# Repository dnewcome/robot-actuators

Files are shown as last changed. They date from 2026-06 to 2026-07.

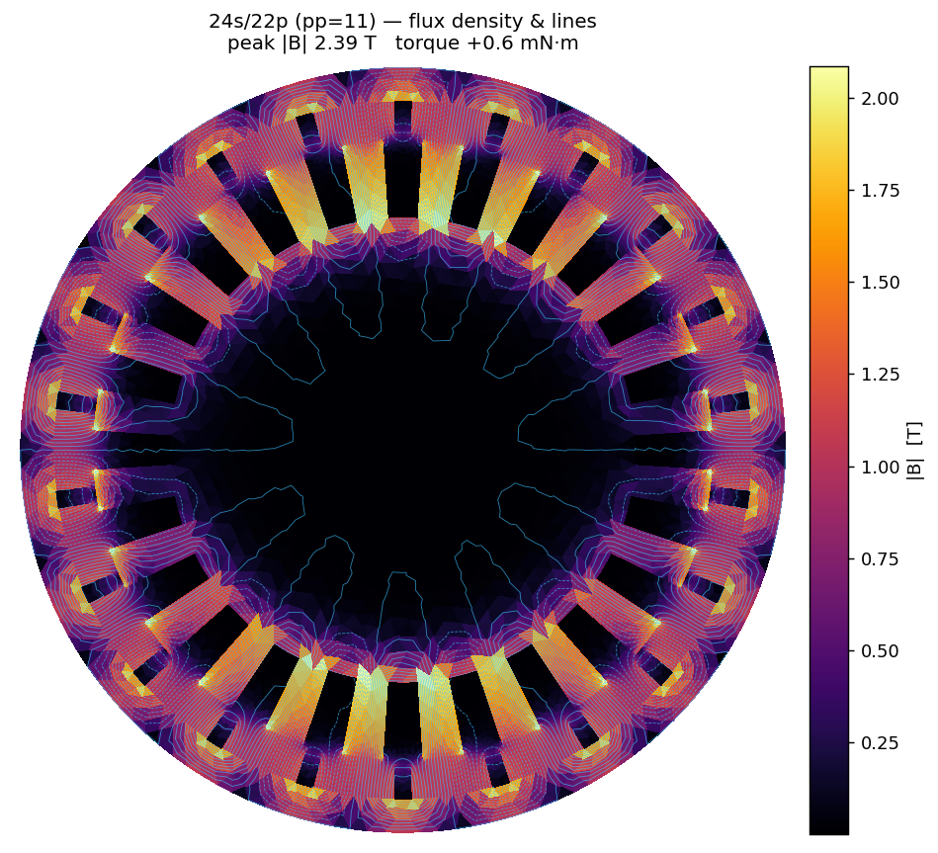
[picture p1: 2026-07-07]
motor/out/field.png

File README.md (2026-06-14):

# Robot Actuators

Designing my own actuators for robot arms (and, longer term, broader robotics /
automation) — and, just as importantly, building a **simulate-first pipeline** so a
parametric CAD design flows straight into a physics sim before anything gets printed
or wired up.

The north star: change a parameter, re-run, and immediately see both the geometry
*and* the predicted torque / speed / inertia behavior — fast enough to screen many
designs without touching a dyno.

---

## The idea

I've used other people's actuator designs (cycloidal drives, etc.) and want to design
my own. The broad wish-list spans very different physics:

- Dyneema capstan / cable drives
- Hybrid electric-hydraulic linear actuators
- Linear brushless motors
- BLDC motors built for servo use (quasi-direct-drive)
- Cycloidal, wave, and harmonic (strain-wave) drives
- Compliant / gearless drives
- Exotic "muscle" actuators — SMA / memory wire, wax motors / heat drives

**Prior experience:** used others' cycloidal drives; experimented with linear actuators
including **peristaltic pumps driving cylinders**; experimented with **wax motors / heat
drives** and **SMA "muscles"** for silent actuation (SMA judged not viable alone, but a
useful jumping-off point).

### The organizing theme

The list isn't "actuators broadly" — the through-line is **quiet, compliant, low/no-gear
actuation for arms.** That filter sorts the list onto a spectrum:

```
  buildable / proven  ─────────────────────────────►  exotic / risky
  Dyneema capstan      QDD BLDC servo        SMA / wax muscle
  (silent, backdrivable,  (force-transparent,   (truly gearless & silent,
   ~95%/stage, light)      low/no gearing)       low η, slow, hard to control)
```

- **Fits the theme:** capstan, QDD-BLDC, exotic muscles.
- **Fights it:** cycloidal / harmonic / wave (geartrains — high torque density but the
  thing we're trying to avoid for silence/compliance) and electro-hydraulic (noisy/messy).
- Cycloidal still wins **when compactness is the binding constraint** — which is exactly
  the case for the current build.

---

## Simulate-first philosophy: two layers

The hard-won insight that shapes this whole repo:

> **MuJoCo cannot tell you the efficiency of a drive.** It's a rigid-body engine for
> *control and whole-system behavior*. When you give a joint a gear ratio and a friction
> loss, you are **typing in** the efficiency, not discovering it. The 70%-vs-90% question
> lives one layer below where MuJoCo operates.

So the problem splits cleanly:

**Layer A — "Does this actuator make the arm work?" → MuJoCo.**
Model each joint with a parametric actuator (gear ratio, reflected inertia, mass, a
load-dependent efficiency, and a back-EMF torque-speed curve). Output: the torque/speed/mass
envelope each joint needs. This is what MuJoCo is good at, and it's wired up today (`mujoco/`).

**Layer B — "Can this drive beat the efficiency ceiling?" → analytical, NOT a sim.**
Capstan efficiency = capstan equation + cable-bend hysteresis + bearing drag; gear
efficiency = mesh-friction formulas. These evaluate in microseconds — faster and more
trustworthy than any sim for *efficiency*. Escalate to FEA / multibody contact only near a
margin. A digital torque meter validates a single point. **Layer B v0 exists**
(`cycloidal/efficiency.py`): it predicts η per contact strategy and feeds that number into
the sim — so the MuJoCo η is no longer a hand-typed guess. The model's coefficients are
*calibration-pending* (one torque-meter point pins them down); the relative ranking of
strategies is already robust (see "Efficiency model" below).

CAD feeds both: mass/inertia → MuJoCo; key dimensions → the analytical model. And the loop
is closed: **Layer B predicts η → Layer A (the sim) consumes it**, all from the same Params.

---

## Repository layout

```
robot-actuators/
├── README.md
├── .venv/                     # python env (build123d, bd_warehouse, mujoco, numpy)
├── cycloidal/
│   ├── drive.py               # parametric build123d generator + feasibility validator (both stages)
│   ├── gears.py               # involute planetary gears: spur (sun/planet) + custom internal ring
│   ├── efficiency.py          # Layer B: two-stage η (planetary × cycloidal) + needle-bearing sweep
│   └── out/                   # generated .step + .stl for all 8 parts + assembly.step
└── mujoco/
    ├── actuator.py            # MotorSpec + ActuatorSpec: motor × total ratio → joint + servo numbers
    ├── testbench.xml          # Layer-A sizing scene (real meshes + load arm + payload)
    ├── run.py                 # injects physics + Layer-B η; runs sizing scenarios; --view demo
    └── viewer_scene.xml       # real-time kinematic demo of the full hybrid (both stages)
```

---

## Quickstart

```bash
# one-time setup
python3 -m venv .venv
.venv/bin/pip install build123d bd_warehouse mujoco numpy   # bd_warehouse = involute spur gears

# 1) generate CAD (edit Params in cycloidal/drive.py, then):
.venv/bin/python cycloidal/drive.py        # prints feasibility report, writes cycloidal/out/*

# 2) Layer-B efficiency model (η per contact strategy + needle-bearing fit sweep):
.venv/bin/python cycloidal/efficiency.py

# 3) actuator spec sheet (motor × gearbox -> joint numbers):
.venv/bin/python mujoco/actuator.py

# 4) Layer-A sizing sim (headless; uses the Layer-B η; prints lift / backdrive scenarios):
.venv/bin/python mujoco/run.py

# 5) look at the mechanism (real-time, needs a display):
.venv/bin/python mujoco/run.py --view
```

> Note: `source .venv/bin/activate` also works, but calling `.venv/bin/python` directly
> avoids the "Permission denied" you get from trying to *execute* `activate` instead of
> sourcing it.

---

## Current build: concentric hybrid planetary + cycloidal (40:1)

A fully **concentric compound**: the motor's high rpm goes through a **planetary first stage**,
whose carrier drives the **cycloidal eccentric**, whose disc drives the output — all on one
axis. Total reduction is the product of the two stages:

```
motor ─► PLANETARY 4:1 (sun in, ring fixed, carrier out) ─► cycloidal ECCENTRIC
      ─► CYCLOIDAL 10:1 (ring fixed, carrier out) ─► output flange      = 40:1
```

**Why split the ratio** (and put the cycloidal *last*):
- The planetary runs at high speed / low torque — the regime where gears are efficient — so a
  small ~97% stage buys 4× ratio cheaply and keeps the cycloidal **chunky** (fat rolling pins,
  healthy eccentricity) instead of forcing tiny high-lobe-count geometry to hit 40:1 alone.
- The cycloidal has the **lowest backlash**, so making it the output stage puts the precision
  where it counts; the planetary's lash divides by the cycloidal ratio when referred to output.

Single-stage cycloidal is still available — set `planetary=False` (ratio falls back to the lobe
count). Compactness is the binding constraint throughout, which is why this beats a capstan here.

### Motor — Goolsky / Surpass 2204 1400KV (measured)

| Spec | Value |
|---|---|
| Can / weight | Ø28 × 22 mm, ~28.7 g |
| Poles / config | 12N / 14P outrunner |
| Shaft | 3 mm, **exits on the mount side** |
| Mount | M3 cross pattern: one hole pair **16 mm** apart, the perpendicular pair **19 mm** apart |
| Electrical | 1400 KV, ~13 A burst, 0.307 Ω, 7–15 V (3S nominal) |

Because the shaft exits the mount side, the gearbox bolts to the motor base and the shaft
drives the eccentric directly — the arrangement the design assumed.

### Planetary stage parameters (all feasibility checks PASS)

| Param | Value | Notes |
|---|---|---|
| Ratio | **4.0:1** | `1 + n_ring/n_sun`; sun in, ring fixed, carrier out |
| Teeth (sun / planet / ring) | 12 / 12 / 36 | `n_ring = n_sun + 2·n_planet`; module 0.75 mm (printable teeth) |
| Planets | 4 | equal-spaced: `(n_sun+n_ring) % n_planets == 0` |
| Gear Ø (PCD) | sun Ø9 / planet Ø9 / ring Ø27 | sun bores over the 3 mm motor shaft |
| Mesh quality | machined (~97%) | `planet_material` sets stage η (`printed` ~94%) |

Geometry is generated as real involute teeth (`cycloidal/gears.py`): external `SpurGear`s for
the sun and planets, and a custom involute **internal** ring gear (no library has one). The
validator checks tooth-count identity, equal-spacing, planet-to-planet collision, ring-fits-
housing, and sun-clears-shaft.

### Cycloidal stage parameters (all feasibility checks PASS)

| Param | Value | Notes |
|---|---|---|
| Ratio | **10:1** | lobe count; 11 ring pins, 10-lobe disc |
| Pin circle / housing OD | Ø32 / Ø39 mm | gearbox is larger than the can, as expected |
| Ring pins | 11 × Ø3 mm | steel dowels / cut rod |
| Eccentricity (E) | 0.70 mm | profile smoothness R/(E·N) = 2.08 (ideal) |
| Center bearing | 6700 (10×15×4) | gives a comfy 2.8 mm eccentric cam wall |
| Output pins | 6 × Ø2.5 mm | 0.85 mm clearance both sides of the lobe-root band |

### The feasibility validator — why it matters

Miniature cycloidals fail on **radial real estate**, not the lobe profile: the eccentric
cam must fit the 3 mm shaft + a wall + the offset + a bearing, and the output-pin circle
must live in the thin band between the center-bearing OD and the lobe root. `drive.py`
reports all those clearances **before** meshing geometry, so an infeasible design is caught
in milliseconds instead of in CAD or on the printer. (It already caught one bad config
during this build.)

Geometry is also checked, not just assumed: the generated disc has the correct **10 lobes**,
lobe depth **1.40 mm = 2E** exactly, and nests inside the Ø32 pin circle.

---

## 3D printing

Every run of `drive.py` writes **watertight STLs** (verified — slicers accept them) plus STEP
files. The parts assemble on a **single axial datum** (`Params.stack()`) into an enclosed can —
the same datum drives the viewer, so the CAD and the animation can't disagree.

| Part | STL bbox (mm) | Role / print notes |
|---|---|---|
| `housing.stl` | Ø40 × 20.5 | integrated case: motor-mount flange + **stepped cavity** (wide for the planetary ring, narrow for the cyclo disc) + cyclo pin pockets + cap bolts. Print flat (flange down). |
| `output_cap.stl` | Ø40 × 8 | end cap with the **688 output-bearing pocket** + hub through-hole + 4 bolts |
| `planet_ring.stl` | Ø34 × 4 | internal involute ring gear; presses into the housing's planetary seat |
| `carrier_eccentric.stl` | Ø30 × 6.5 | **merged** planet carrier + eccentric journal; planet-dowel holes + offset cam boss |
| `disc.stl` | Ø30 × 5 | the cycloidal disc; print flat, fine layers (0.1 mm) for the lobe profile |
| `output_carrier.stl` | Ø26 × 9.5 | output flange + **Ø8 hub** (the output shaft, rides in the cap bearing) |
| `sun.stl` / `planet.stl` | Ø10.5 × 4 | module-0.75 involute gears (sun bored for the shaft, planets for their dowels) |

**Bill of non-printed materials** (`drive.py`'s `hardware_bom()`):
- 11 × Ø3 mm steel dowel (ring pins — **free-spinning** rollers in the default `pin_mode="rolling"`)
- 6 × Ø2.5 mm steel dowel (output pins — pressed into the output carrier)
- 4 × Ø1.5 mm steel dowel (**planet idlers** — press into the carrier; planets spin on these)
- 1 × **6700** bearing (10×15×4) on the carrier's eccentric journal
- 1 × **688** bearing (8×16×5) in the end cap (output support)
- **planetary gearset** — Ø9 sun + 4 × Ø9 planet + Ø27 internal ring, module 0.75 (machined/MOD
  gears for η + durability, or SLA-printed for a prototype)
- 8 × M3 screws (4 motor cross-mount @ 16/19 mm + 4 end-cap)
- the Goolsky 2204 motor

> **Status — assembles into a printable can, not yet a finished drive.** The 8 parts now sit on
> a shared datum into an enclosed, supported actuator (motor flange ↔ output-bearing cap), with
> module-0.75 filleted gears, steel-dowel planet idlers, and explicit running/press clearances.
> Still to detail (see Roadmap): the motor **pilot boss**, the disc↔output-pin tolerances on your
> printer, and a balancing second disc. Gears at module 0.75 are printable on a 12k SLA but are
> still the first candidates to *machine/buy*. PETG or filled nylon recommended for the disc/cam.

## Manufacturing strategy: print the structure, machine the contacts

A cycloidal's efficiency lives almost entirely in a few **contact interfaces**, not in the
bulk parts. So the rule this project follows:

- **3D print the structure** — ring/housing body, carrier body, motor adapter. These just
  locate things; a 12k SLA gives accurate bores and bolt patterns, and resin tackiness
  doesn't matter where nothing slides.
- **Don't print the contact surfaces.** The places that rub set η, and SLA ABS-like resin
  is tacky (high μ) and wears under Hertzian contact — the worst material exactly where it
  matters most. This is *why* "print the housing, machine/buy everything else" is the right
  instinct.

The contacts, in order of efficiency leverage:

| Interface | Carries | v1 default | Efficiency upgrade |
|---|---|---|---|
| Eccentric ↔ disc center | radial reduction load | **6700 bearing** (already rolling) | — |
| Ring pin ↔ disc lobe | main reduction torque | fixed Ø3 steel dowel (**sliding**) | **rotating roller**: dowel core + hardened sleeve / needle bearing → rolling |
| Output pin ↔ disc hole | output torque | integral printed pin (sliding) | steel pin + **bronze / IGUS bushing or roller** |

**Biggest single lever: make the ring pins rotate.** A fixed pin *slides* against the lobe
(high loss); a pin (or sleeve) that *spins* turns that into rolling contact. This is most of
what separates a ~70% printed cycloidal from a ~90% one — largely independent of disc
material.

**The disc** is the other variable: SLA-print it for a prototype (12k gives a smooth lobe
profile, but tacky resin + wear cap durability and η), or step up to **machined POM/acetal**
(self-lubricating, low μ, cheap to machine) or metal for the real article. If the pins roll,
disc material matters mostly for *wear*, not friction.

This is also the **Layer B bridge**: which contacts roll vs slide, and the materials' μ, are
exactly the inputs the analytical efficiency model needs. The manufacturing choice and the
efficiency prediction are the same decision.

**This is now a `Param`, not a note.** `drive.py` encodes the contact strategy directly:

| Param | Options | Effect |
|---|---|---|
| `pin_mode` | `"fixed"` \| `"rolling"` (default) | press-fit dowel (sliding) vs free-spinning dowel in an oversized pocket (rolling) |
| `pin_core_dia` | `≤ pin_dia` | set `< pin_dia` for a hardened sleeve on a thin core (validator checks the sleeve wall) |
| `out_mode` | `"printed"` \| `"steel"` (default) \| `"bushing"` | integral printed pins (sliding) → pressed steel pins (sliding, good surface) → core + rotating bushing (rolling) |

The validator prints the resulting **contact strategy** (`ROLLING`/`SLIDING` per interface)
and checks sleeve/bushing wall thicknesses; `hardware_bom()` lists exactly what to buy for
the chosen modes. True rolling bushings on the *output* pins are tight at Ø2.5 — the
pragmatic default is rolling ring pins + pressed steel output pins.

## Efficiency model (Layer B v0) — can rolling elements help?

`cycloidal/efficiency.py` is the analytical half of Layer B. It predicts η from the contact
strategy (friction-coefficient based, coefficients **calibration-pending** — one torque-meter
point tunes them) and feeds that number straight into the sim. Predicted η by strategy:

| Strategy | ring / output contact | predicted η |
|---|---|---|
| all printed (worst) | sliding / sliding | ~65% |
| steel pins, sliding | sliding / sliding | ~77% |
| **default: rolling pins + steel output** | rolling / sliding | **~86%** |
| sleeves both | rolling / rolling | ~90% |
| needle bearings everywhere | rolling / rolling | ~93% |

**The finding:** most of the gain (65 → 86%, **+21 points**) is already captured by the cheap
default — free-spinning ring pins. Going further to full needle bearings adds only **+4–7
points**, and at this size it's mechanically awkward:

```
needle-bearing fit sweep (current Ø3 pins, housing Ø39):
  Ø2.5 loose-needle build ...... drop-in (replaces current pins)
  Ø4 loose-needle .............. grow drive to Ø26
  HK0408 drawn cup (Ø8) ........ grow drive to Ø44
  HK0509 drawn cup (Ø9) ........ grow drive to Ø48
```

So: **rolling ring pins are the high-value move; needle bearings are diminishing returns**
that cost compactness — unless you build the marginal Ø2.5 loose-needle rollers, which fit
as-is. The model's *relative* ranking is robust (driven by μ ratios); the absolute numbers
wait on the torque meter.

## How it's wired (single source of truth)

```
cycloidal/drive.py  ──(ratio)──►  mujoco/actuator.py  ──►  mujoco/run.py
      │                                                         │
      └──► out/*.stl ─────────────────► testbench.xml ◄─────────┘
                                        viewer_scene.xml
```

The **total ratio** (`planet_ratio × cyclo_ratio`) is pulled straight out of `drive.py` into
`actuator.py`, and `run.py` injects the derived armature / gear / friction onto the MuJoCo model
at load time. **Change a `Param`, re-run, and the geometry and the sim move together** — they
can't drift apart. `p.ratio` is the single number the whole sim sees, so going hybrid changed
nothing downstream except the value.

`actuator.py` turns motor constants × ratio into joint-level numbers:
`Kt = 60/(2π·KV)`, `peak τ = η∞·Kt·I·N − drag`, `no-load ω = KV·V/N`, `reflected J = J_rotor·N²`,
and the back-EMF current limit `I = (throttle·V − Ke·ω)/R`. η∞ now chains both stages
(`η_planet × η_cyclo`) and `drag` refers through the full ratio — both from `efficiency.py`
(Layer B), so the whole chain is one source of truth.

### Positioning / servo resolution (BLDC "step counts")

A BLDC has no native steps like a stepper — but **the reduction multiplies whatever the rotor
resolves**, which is the lever for servo accuracy. For the 14-pole motor (7 pole-pairs) at 40:1:

| Rotor sensing | counts / motor rev | × 40 → output | output resolution | holds at standstill? |
|---|---|---|---|---|
| Hall / back-EMF 6-step | 6 × 7 = 42 | 1,680 | **0.214°** | Halls yes; back-EMF **no** |
| magnetic encoder 14-bit | 16,384 | 655,360 | ~0.001° | yes (FOC) |

Output **backlash ~0.08°** (planet lash ÷ cyclo ratio + tiny cyclo lash) sits below the Hall
resolution, so 0.214° is usable, not swamped by slop — that's *why* the cycloidal is last.
**Back-EMF amplitude ∝ speed**, so it gives commutation + velocity for efficient cruising but
**cannot hold position at rest**; pair it with Halls (cheap 0.214°) or an encoder (precise) for
the holding loop. `actuator.py`'s `servo_report()` prints this table for the current Params.

### Torque-based (load-dependent) efficiency

Efficiency isn't a flat number — a roughly constant **no-load drag** must be overcome before
useful torque appears, so η rises from 0 toward η∞ as load grows. This is realized in the sim
for free: **gear carries η∞ (0.83), joint frictionloss carries the drag (80 mN·m at output)**,
which reproduces `η(T) = η∞·T/(T+drag)`. The *operating* efficiency therefore tops out ~81% at
peak torque (peak load ≠ infinite load), not 83%. η∞ is itself the two-stage product
(planetary 0.97 × cyclo 0.86).

### Back-EMF and the torque-speed curve

The motor is now driven by **throttle (voltage)**, not raw current. At speed it generates
back-EMF (`Ke = Kt`), so the available current is `I = (throttle·V − Ke·ω) / R`, clamped to
the 13 A rating. That yields the real two-regime envelope:

- **current-limited** (flat ~2.87 N·m) below the corner speed (~249 rpm out), where the rating
  caps the current;
- **voltage-limited** above it, torque drooping linearly to **zero at the 388 rpm no-load
  speed** as back-EMF eats the headroom.

No more freewheeling: a free spin settles at no-load speed instead of accelerating forever.

---

## Simulation results (hybrid 40:1, load-dependent η, η∞ = 0.83)

```
total ratio ....... 40:1       (planetary 4.0 × cycloidal 10)
η∞ (high-load) .... 83%        (planetary 0.97 × cyclo 0.86); no-load drag 80 mN·m (output)
PEAK torque ....... 2.87 N·m   (@ 13 A burst, net of drag)
cont. torque ~..... 0.89 N·m   (thermal-limited estimate)
no-load out speed . 388 rpm
reflected inertia . 24e-4 kg·m²   (scales with ratio²)
max static payload  ~1.95 kg @ 150 mm (peak) / ~0.61 kg (continuous)
output resolution . 0.214° (Hall × 40)   backlash ~0.08°
```

**Scenario A — free accel:** output reaches ~30 rad/s in 50 ms; simulated effective
inertia (46.8e-4) **matches the hand calc** of arm+payload+armature → the model is
trustworthy.
**Scenario B — lift 100 g @ 150 mm:** needs 0.16 of 2.87 N·m available → lifts easily.
**Scenario C — unpowered hold:** backdrives under load → **backdrivable**, the desired
property for a compliant, safe arm.
**Scenario D — efficiency vs load (measured in sim):** η climbs 32% → 46% → 59% → 69% as
output torque rises 0.05 → 0.40 N·m, and the **measured η matches the model** — the load
curve emerges from the gear+frictionloss physics, not a typed-in constant.
**Scenario E — torque-speed curve (traced in a sim spin-up):** under full throttle the
delivered torque holds ~2.87 N·m to ~249 rpm, then droops toward zero at 388 rpm — the
back-EMF envelope, measured as the output accelerates (sample points scale with no-load speed).

The `--view` demo is a real-time kinematic scene of the **whole hybrid**: the cycloidal
**output** turns at 0.25 rev/s, the **planet carrier** at 10×, the **gold sun** at 40×, and the
**4 green planets** orbit (10×) while spinning on their pins (−20×) — the full 40:1 chain visible
at a glance.

---

## Roadmap

**The exciting frontier: a full electromechanical drive model.** Done so far: efficiency is
**load-dependent** (η rises with torque ✓), **geometry-driven** (predicted from the contact
strategy ✓ Layer B v0), and the motor now has **back-EMF + a real torque-speed curve** driven
by throttle/voltage with current limiting (✓). What's left:

- **Winding inductance (L) + fast current dynamics** — the steady-state electrical model (R,
  V, back-EMF, current limit) is in; add L and explicit FOC for transient current response.
- **Thermal** — I²R heating → the *real* continuous-torque limit instead of a 1/3 guess.
- **Load-dependent bearing losses** — extend Layer B so the drag itself grows with the mesh
  force (the eccentric bearing reacts the load), refining the low-load end of the η curve.

One CAD edit already predicts geometry → efficiency(load) → torque-speed behavior before any
hardware exists. Remaining items refine transients (L/FOC) and thermal limits.

**Nearer-term:**
- **Calibrate the Layer B model** with one torque-meter point (the v0 model exists and feeds
  the sim; the coefficients are still estimates). Extend it with load-dependent bearing losses.
- Drop this actuator into the real arm MJCF as a reusable joint module.
- Detail the last hardware bits: motor **pilot boss**, disc↔output-pin tolerances, and the
  output shaft / arm-joint interface.
- Add a second cycloidal disc at 180° (or a counterweight) to balance before high rpm.
- Sweep the total ratio: bump to **44:1** (cyclo 11 lobes) or **48:1** (cyclo 12), or shrink the
  Ø40 case now that clearances are visible.
- Planetary detailing: backlash/profile-shift on the gears for real print fit.

**Done this iteration:** **integrated, printable assembly** — one enclosing case (motor flange +
stepped cavity + cyclo pockets) with a 688-supported output cap, module-0.75 filleted gears,
steel-dowel planet idlers, merged carrier+eccentric, and a single `stack()` datum shared by the
CAD assembly and the viewer (parts no longer interpenetrate).

**Prior iteration:** concentric **hybrid planetary + cycloidal (40:1)** — involute gears
generated (`gears.py`), two-stage η chained, total ratio flows through the whole sim, the full
compound animates in `--view`, and the BLDC **servo-resolution** model (ratio as a position
multiplier) is in `actuator.py`.

---

## Backlog / parked ideas

- QDD BLDC servo (Mini Cheetah / MIT style) — the modern quiet-arm path.
- SMA / wax "muscle" test rig — silent & gearless, high risk; research, not a deliverable.
- Electro-hydraulic linear actuators; peristaltic-pump-driven cylinders.
- Capstan / cable drive — the high-efficiency, silent play for when compactness isn't binding.
- Harmonic / wave drives; linear brushless motors.
- Broader "silent drive" survey.

---

## Caveats baked into the code

- **η is model-derived but calibration-pending.** Efficiency now comes from the Layer-B
  contact model (η∞ ≈ 0.86), is load-dependent, and feeds the sim — but the model's
  coefficients are estimates. One torque-meter point (no-load drag → `drag`; a loaded point →
  η∞) locks the absolute numbers. The *shape* (load-dependent, geometry-driven) is right; the
  *absolute* values aren't validated yet.
- **Electrical model is steady-state.** Back-EMF, resistance, bus voltage, and the current
  limit are in (real torque-speed curve), but winding inductance (L) and explicit FOC current
  dynamics are not — transient current response is idealized. Fine for sizing/torque-speed.
- **Continuous torque is a guess** (~1/3 of peak) until a thermal model replaces it.
- **The kinematic viewer treats the rotor as rigid** — the cycloidal disc's nutation isn't
  animated (it's a look-at-the-mechanism demo, not a contact simulation).

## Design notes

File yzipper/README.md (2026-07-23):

# Y-zipper — 3-strip flexible↔rigid element (paper-faithful rebuild)

*Rebuilt 2026-07-23 to follow the paper's ACTUAL algorithm (an earlier version used a
made-up "differential pitch → radius" rule + rectangular teeth, which did not match the
paper — the shapes came out wrong). Now grounded in Jiaji Li et al., "Y-zipper", ACM
CHI '26 — [doi:10.1145/3772318.3790723](https://dl.acm.org/doi/10.1145/3772318.3790723),
§3.1 (tooth geometry) + Appendix A.3 (primitive formulas).*

*A stiffness element, not a linear actuator — the actuator sibling is the 2-strip zip
chain in [`../zipchain/`](../zipchain/). The "actuator" here is the slider.*

> **Hardware in progress (2026-07-22):** test-printing a community "extended / optimized"
> three-sided Y-zipper ([MakerWorld 2888456](https://makerworld.com/en/models/2888456-y-zipper-extended-optimized-three-sided-zipper)).
> The measured per-tooth engagement force and the screw constant `k` are the two
> calibration-pending inputs the print pins down.

---

## Tooth geometry (§3.1) — what was wrong before

Each vertical **segment** is three teeth (a, b, c) with a **wave-like profile** that
**cyclically overlap** — left of a over right of b, b over c, c over a — a mutually
supporting ring that turns three flexible strips into a rigid triangular prism. Each
tooth carries a **ball node (∅1 = 2.4 mm)** on top and a **socket (∅2 = 3.0 mm)** below
(tol 0.3 mm) for shear/alignment, and **compliant bridges** (thickness D; TPU 0.6–2.4,
PLA 0.4–1.2) join segments and carry tension when zipped. *(The old model used uniform
rectangular castellations with none of this — hence "the output doesn't look right".)*

## Programming shapes = varying the teeth (Appendix A.3)

The four one-DOF primitives are **not** made by changing pitch; they come from the tooth
geometry:

| Primitive | Mechanism | Formula |
|---|---|---|
| **Straight** | uniform teeth | `z = v·t` |
| **Bend** | teeth at interface α–β **thinner** than α–γ; accumulate `T1, T2` | **θ = 2(T1−T2)/(√3·w)**,  **R = (T1+T2)/(2θ)** |
| **Screw** | shift each tooth's lower side up by Δt → ball-normal rotates | **θ_z = k·Δt**  (−1.5t ≤ Δt ≤ 2.5t),  L_z = √(L²−(r·θ_z)²), r = w/√3 |
| **Coil** | bend **+** axial rise Δz per segment | helix R, pitch h from `T1,T2,T3,Δz` |
| **Series** | primitives compose via homogeneous transforms | `r(t) = Σ Tᵢ₋₁·rᵢ(tᵢ)` |

The bend is a *bimetallic-strip* effect: a difference in accumulated tooth **thickness**
across the two interfaces, over the interface separation √3·w/2 (the triangle height),
bends the axis. `yzipper.py` also exposes the **design inverse** the Grasshopper tool
gives users: the (T1−T2) needed for a target angle (bend 90° → T1−T2 = 34.0 mm at w=25).

## Stiffness — the paper's MEASURED values (not an idealized calc)

Three-point bending (§9.2): **EI_strip ≈ 1.9×10³ → EI_rod ≈ 3.1×10⁵ N·mm² ≈ 160×**.
Beam stiffness `k = 48·EI/L³`; max load rises with bridge D (11 kg @ 0.8 mm → 18 kg @
2.0 mm). *(An idealized closed-thin-wall calc overpredicts ~400× because teeth + bridges
are not a solid tube — so the model is anchored to the measured numbers.)*

## Files

- **`yzipper.py`** — the primitive algorithm: `inc_straight/inc_bend/inc_screw/inc_coil`
  build each primitive from the Appendix A.3 equations, `_integrate` composes them via
  homogeneous transforms, and `out/primitives.png` **reproduces the paper's Fig. 6**
  (straight prism, bend arch, coil helix, screw twist, and a straight+90°-bend series).
  Calibrated stiffness/load report.
- **`cad.py`** — corrected tooth geometry: rounded **wave teeth + ball nodes + sockets +
  bridges** (`strip_straight`), and a **curved arc flat-pattern with differential tooth
  spacing** (`strip_bend`) that embodies the θ = 2(T1−T2)/(√3·w) bend; plus the 3-way
  `slider` and a `segment` prism. All watertight solids.
- **`sim.py`** — MuJoCo viewer: the closed rod is instanced along a paper-equation
  centreline; the slider zips base→tip and the **rigid (zipped) front advances** while
  the unzipped part stays translucent. `make sim-yzipper` (bend) / `sim.py coil`.

`make yzipper / yzipper-cad / sim-yzipper`.

---

## Sources
- Paper (open access PDF): https://groups.csail.mit.edu/hcie/files/research-projects/y-zipper/y-zipper.pdf
- Paper (ACM CHI '26): https://dl.acm.org/doi/10.1145/3772318.3790723
- Project page / video: https://hcie.csail.mit.edu/  · https://www.youtube.com/watch?v=AWig98GVIno
- Printable model being tested: https://makerworld.com/en/models/2888456-y-zipper-extended-optimized-three-sided-zipper

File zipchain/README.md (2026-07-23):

# Zip-chain linear actuator — research + Layer-B model

*Built 2026-07-22: `zipchain.py` (model) + `cad.py` + `sim.py`. This is **one of two
separate zipper-for-rigidity mechanisms** in the repo — the **LINEAR ACTUATOR**. Its
sibling, the **Y-zipper variable-stiffness element**, is a **different mechanism for a
different purpose** and lives in [`../yzipper/`](../yzipper/). They share only the
"mesh to make rigidity" trick; as devices they do different jobs — don't conflate them.*

| | **zip chain** (here) | **Y-zipper** ([`../yzipper/`](../yzipper/)) |
|---|---|---|
| strips | **2** | **3** |
| output | linear **thrust + stroke** (motion) | a **stiffness state** (flex↔rigid) |
| section | open, needs a guide | closed triangle, self-supporting |
| role | a linear **actuator** | a variable-stiffness / deployable **structure** |
| binding constraint | column **buckling** | tooth engagement / section stiffness |

---

## The mechanism (Tsubaki reference)

Two chain strands are fed into a sprocket head where they **interlock like a zipper**
into a single rigid pillar; run the sprocket backward and they separate and re-coil.
A normal chain only pulls — this one **pushes and pulls**, because the meshed column
carries compression, and the mesh **self-locks** so it holds a load with the motor off.

**Why it's genuinely different** from a ball screw / rack-and-pinion:
- **Compact storage → long stroke.** The strands store as two coils and deploy into a
  rigid strut (Tsubaki claims up to ~90% less floor area for a given stroke).
- **Push *and* pull** over the full stroke (rigid chain, not a cable).
- **Self-locking hold** at any position **without power** — ball screws can't.
- **Cheap to run** — < 1/30 the power of a comparable pneumatic/hydraulic cylinder.

Reference specs (industrial Zip Chain Actuator, medium/large): **38.2 kN**, **5,000 mm**
stroke, **1,000 mm/s**, **~90%** efficient with dedicated sprockets, 6M round trips,
multi-point stop, vertical-lift / horizontal-push / vertical-hang mounting.

## Why 2 strips — and why 3 is a different animal

Two strands zipped make an **open, near-flat section**: stiff to **in-plane** bending
only, weak out-of-plane and in torsion. Tsubaki gets away with it because the sprocket
**housing guides the weak axis** — it's a *guided push rod*. Add a third strip at 120°
and you get a **closed triangular tube** — rigid in every direction plus torsion, and
**self-supporting** with no guide. That extra rigidity is a different capability for a
different job (a stiffenable structure, not a push actuator) → it's the [`yzipper/`](../yzipper/)
thread, not this one.

## Fit to this repo

A **linear-actuator** cousin to `linear/` and `linear-rail-servo/`, but with a *different*
binding constraint — **column buckling**, not fluid compressibility or belt backlash. It
is **non-backdrivable with an energy-free hold**, which *fights* the repo's
quiet/compliant/backdrivable theme (like cycloidal does) yet **wins when the need is a
compact linear push that holds position with the motor off.** PLA-printable.

## The Layer-B model (BUILT — `zipchain.py`)

> **The binding constraint is COLUMN BUCKLING, not the motor.** The deployed free length
> is an Euler strut, so push capacity **falls as it extends**: `F_cr(L)=π²·E·I_col/(k·L)²`.
> Below a knee length **L\*** the actuator is drive/mesh-limited (flat); beyond L\* it is
> buckling-limited (∝1/L²). The push–stroke envelope is therefore **asymmetric** from the
> pull side (tension-limited by strand strength). `zipchain.py` exposes that envelope, a
> feasibility validator, and `out/envelope.png`.

Three design levers, all `Param`s: **column stiffness E·I** (section × engagement
fraction), **sprocket pitch radius r_p** (the gear ratio — trades thrust for deploy
speed, power-conserving), **end fixity k** (k=2 fixed-free cantilever conservative;
guided load end → k=1 quadruples F_cr).

**Default design results** (robot-scale, printed; calibration-pending strengths):

| Quantity | Value |
|---|---|
| deploy speed | **607 mm/s** @ 300 rpm (r_p = 19.3 mm, z=12) |
| drive thrust (τ/r_p) | **93 N** @ 2.0 N·m |
| push envelope | **93 N flat → 39 N** at full 320 mm extension |
| **buckling knee L\*** | **207 mm** (last ~⅓ of stroke is buckling-limited) |
| pull | 93 N flat (drive-limited; strand cap 1500 N) |
| hold @ full ext, motor off | **39 N** (mesh self-locks) |
| stored footprint | Ø81 mm for 300 mm stroke (store/stroke **0.27**) |

**`cad.py`** — 3 watertight solids: `strand` (a comb: outer spine + interlacing fingers),
`sprocket` (bored disc + z teeth), `head` (guide/merge housing that constrains the weak
axis). Two mirrored/half-pitch-staggered strands interlace into the deployed column.

**`sim.py`** — kinematic MuJoCo viewer: sprocket spin geared to column extension
(x=r_p·θ), column fed through the head; the montage annotates each frame with the push
capacity at that extension, so you watch the buckling ceiling fall as it deploys.
`make zipchain / zipchain-cad / sim-zipchain`.

---

## Sources
- Tsubaki Zip Chain (technology): https://en.tt-net.tsubakimoto.co.jp/tecs/pdct/sad/feat/pdct_feat_sad_ZC.asp
- Tsubaki Zip Chain Actuator (product): https://www.ustsubaki.com/products/zip-chain-actuator/

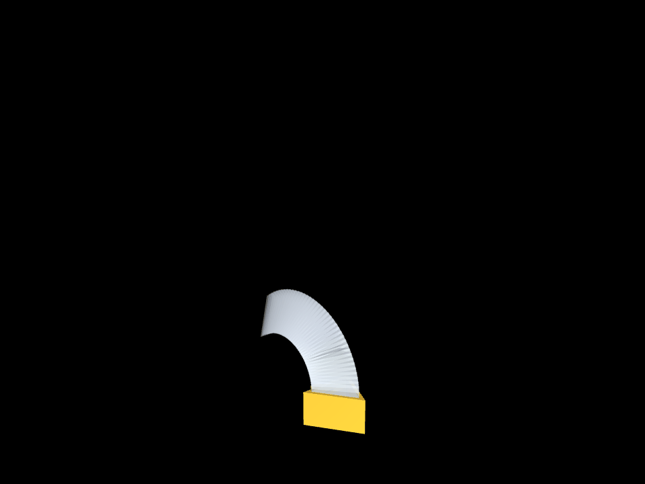
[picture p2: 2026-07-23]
yzipper/out/sim.gif

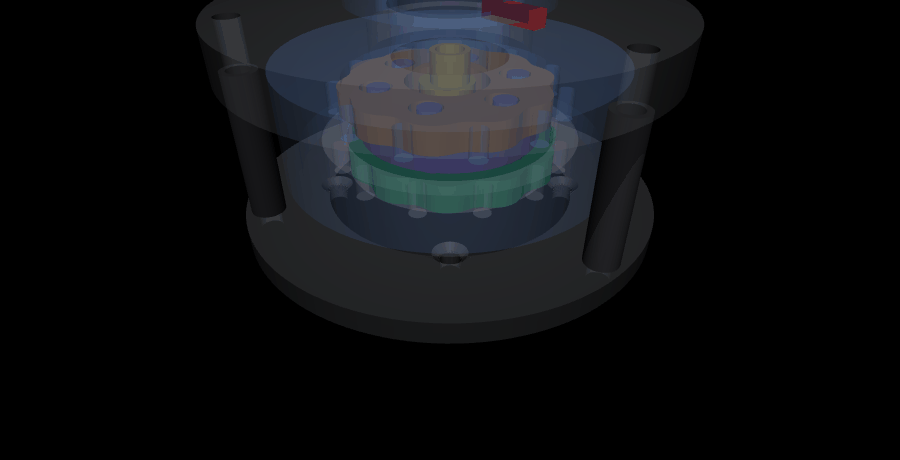
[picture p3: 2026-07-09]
cycloidal-2stage/out/sim.gif

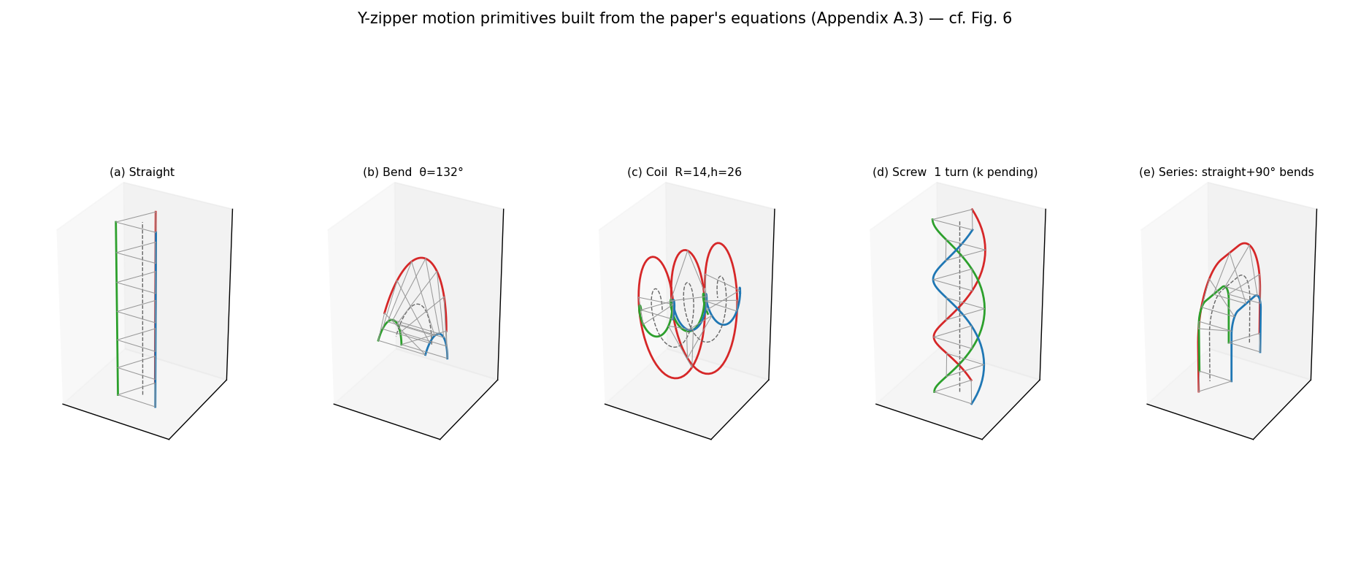
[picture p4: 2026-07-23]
yzipper/out/primitives.png

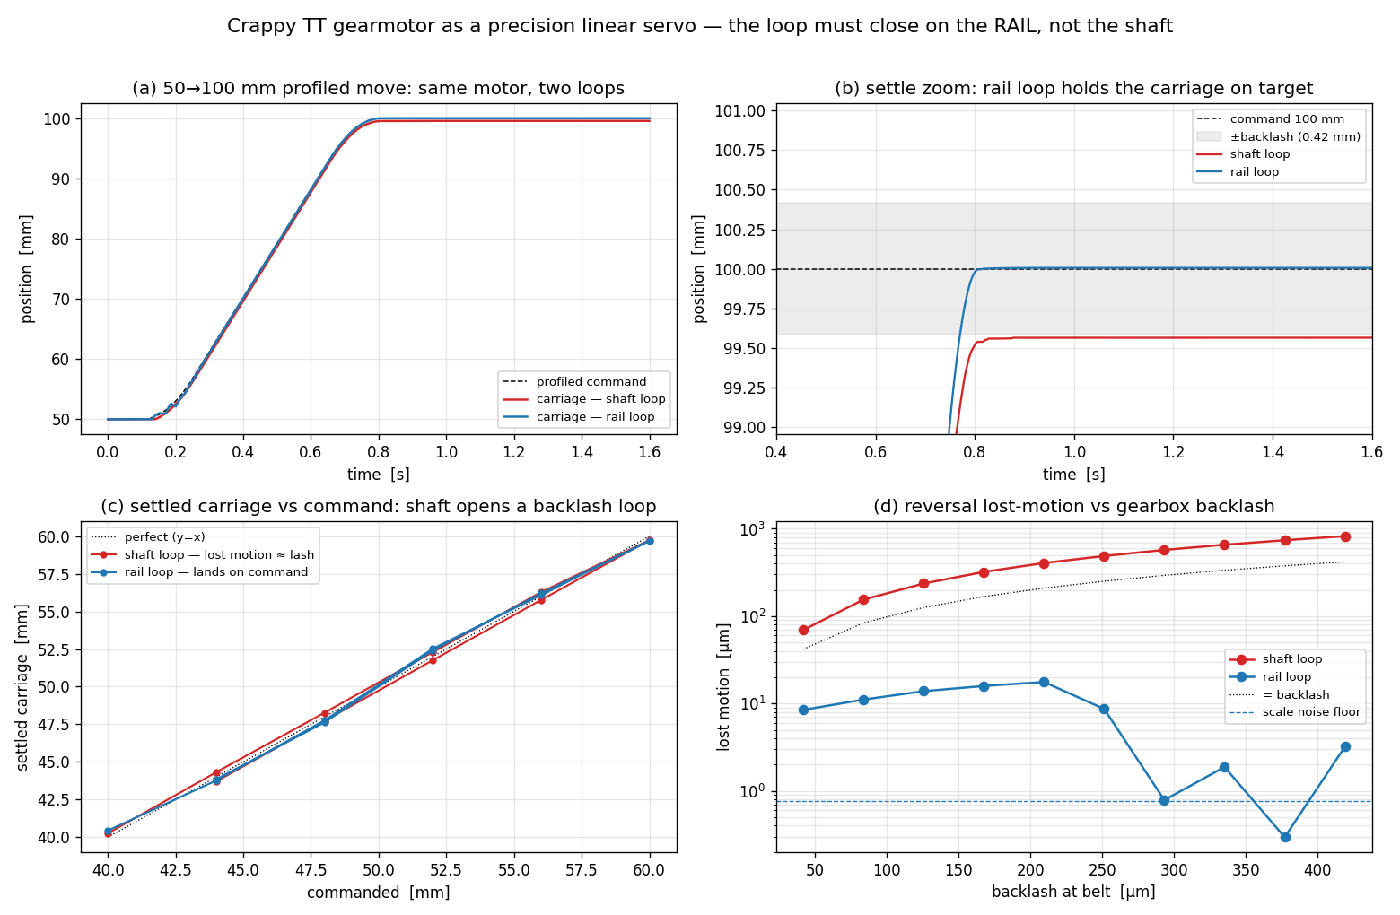
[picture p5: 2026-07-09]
linear-rail-servo/out/servo.png

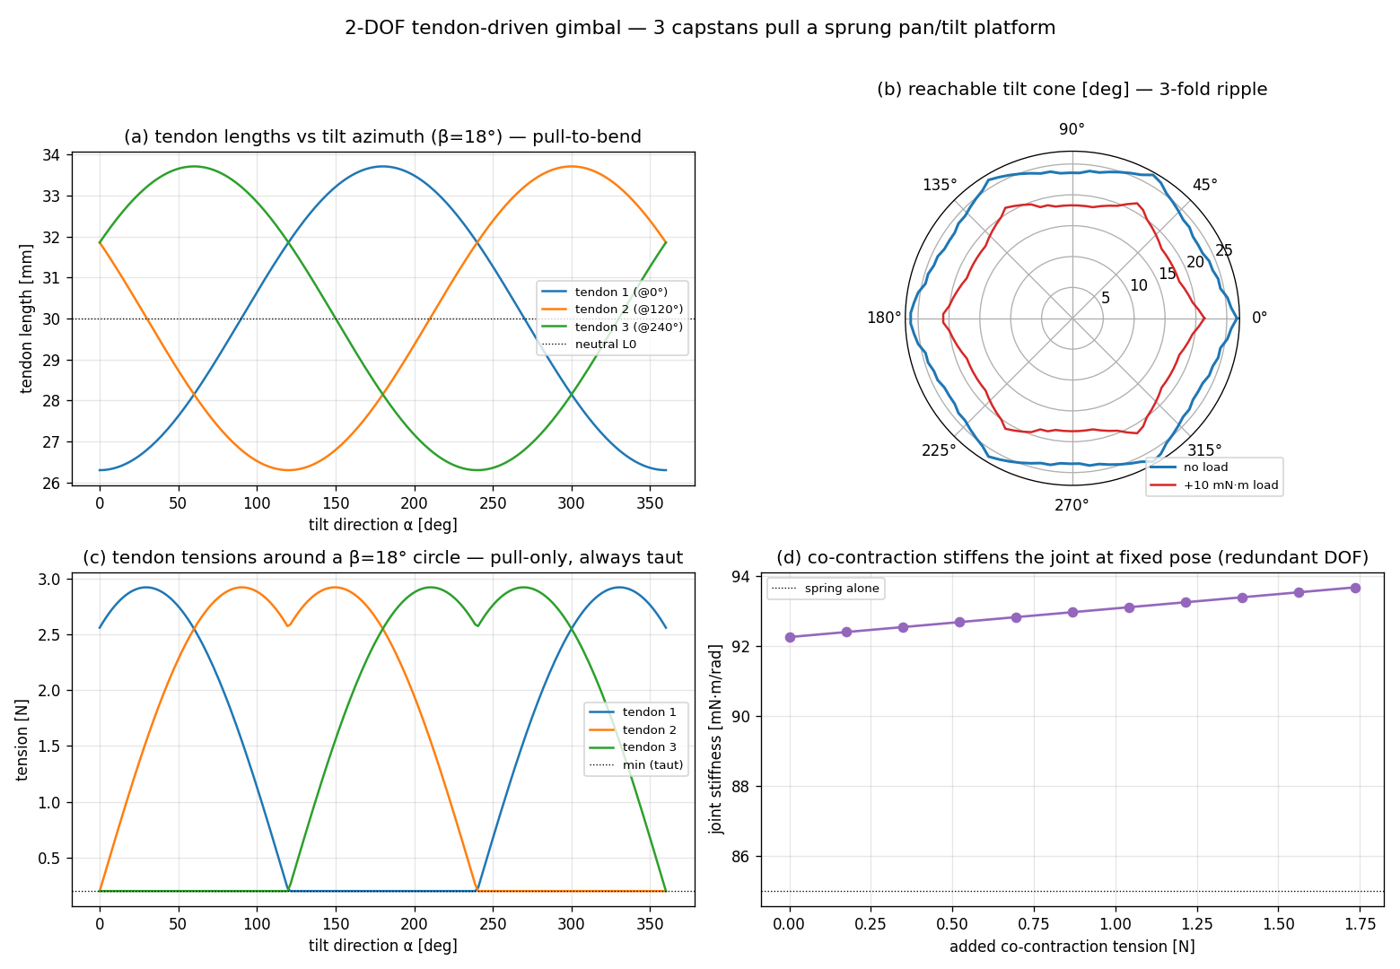
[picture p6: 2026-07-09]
flex/out/flex.png

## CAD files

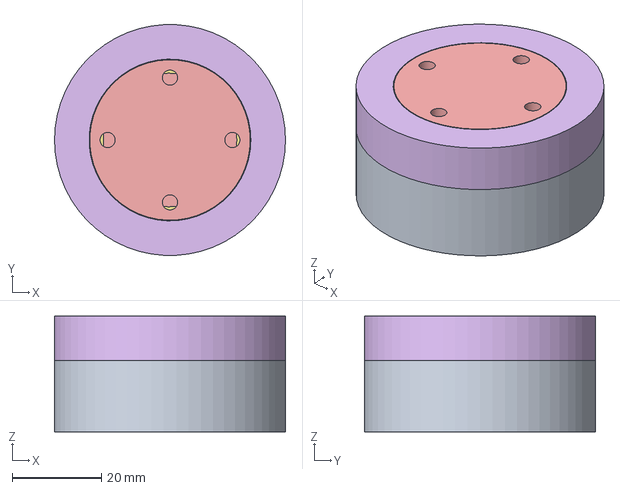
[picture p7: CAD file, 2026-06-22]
cycloidal-center/out/assembly_full.step
51.8 x 51.8 x 26.0 mm

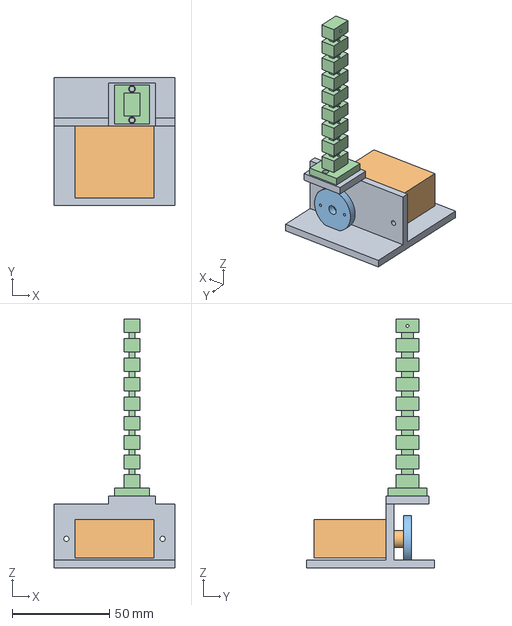
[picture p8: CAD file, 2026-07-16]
tendril/out/assembly.step
62.0 x 66.0 x 128.0 mm

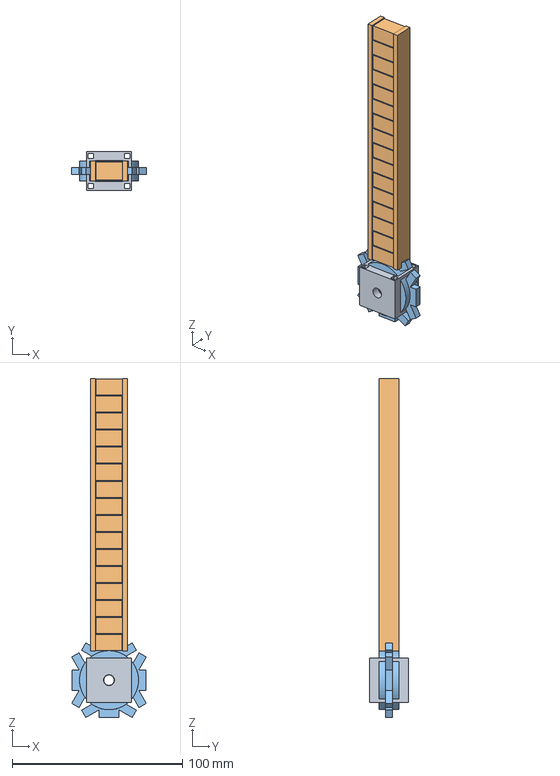
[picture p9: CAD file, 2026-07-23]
zipchain/out/assembly.step
43.8 x 22.6 x 198.9 mm

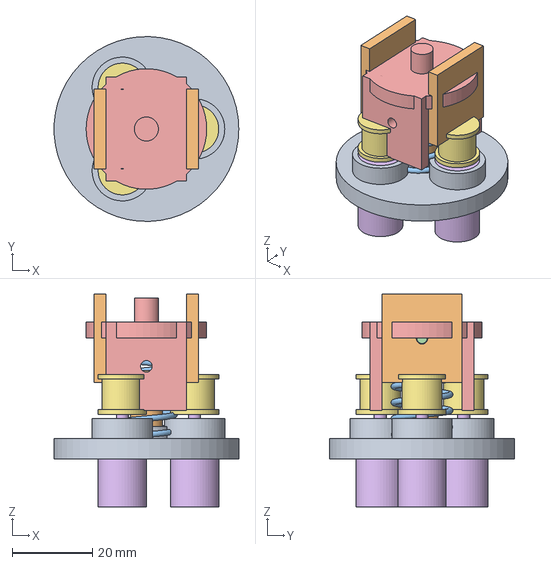
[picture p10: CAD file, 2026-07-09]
flex/out/assembly.step
46.0 x 46.0 x 53.0 mm

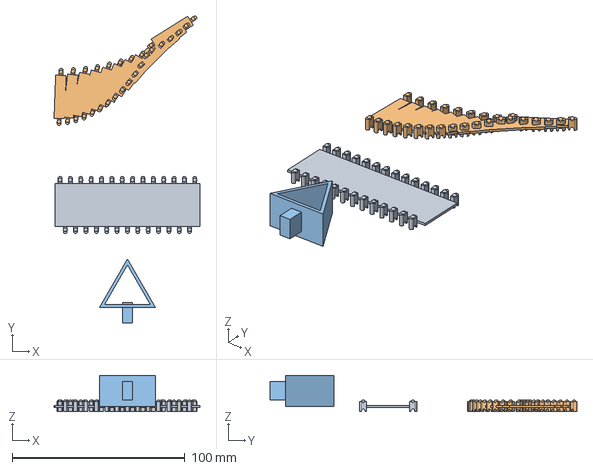
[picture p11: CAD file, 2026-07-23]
yzipper/out/assembly.step
84.5 x 177.7 x 21.0 mm

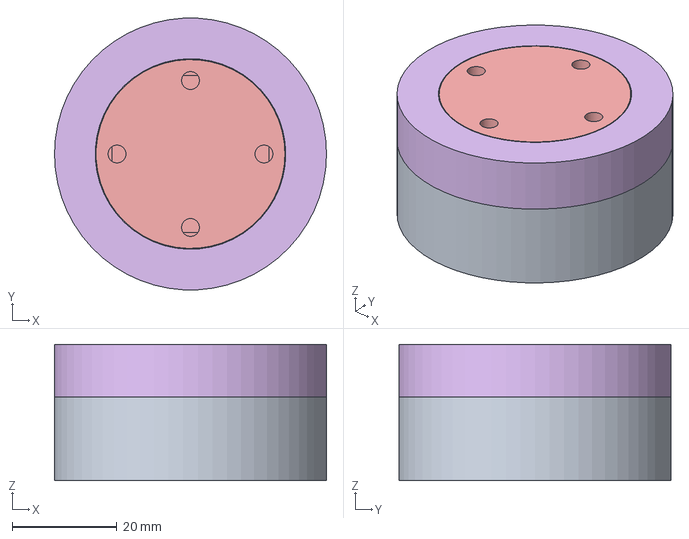
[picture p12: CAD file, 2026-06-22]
cycloidal-center/out/assembly.step
51.8 x 51.8 x 26.0 mm

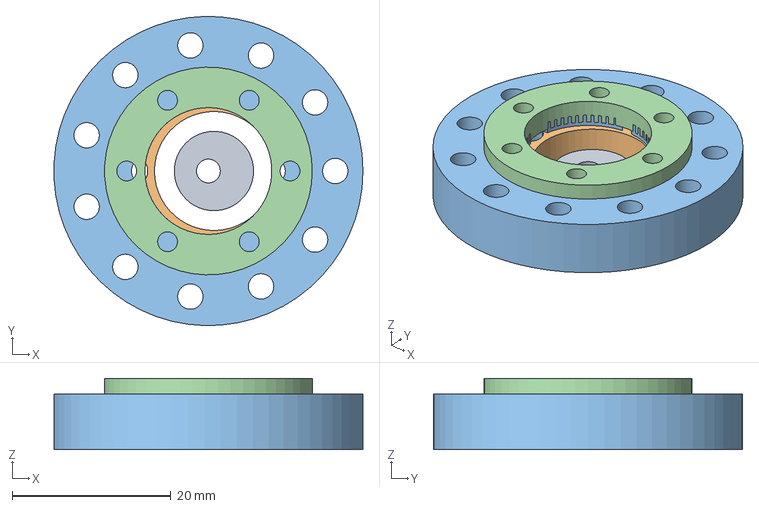
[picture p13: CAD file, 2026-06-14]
cycloidal/out/assembly.step
39.0 x 39.0 x 9.00 mm

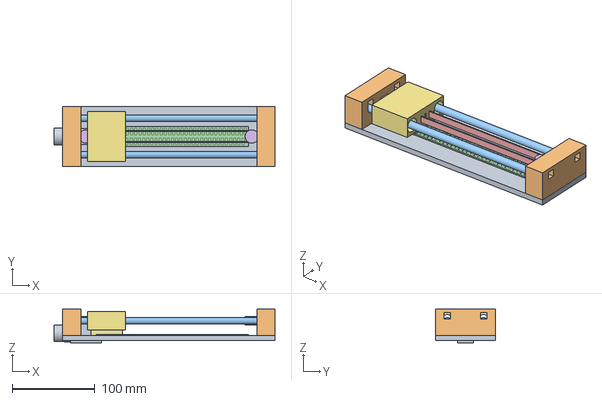
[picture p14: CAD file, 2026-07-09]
linear-rail-servo/out/assembly.step
266.5 x 72.0 x 40.6 mm

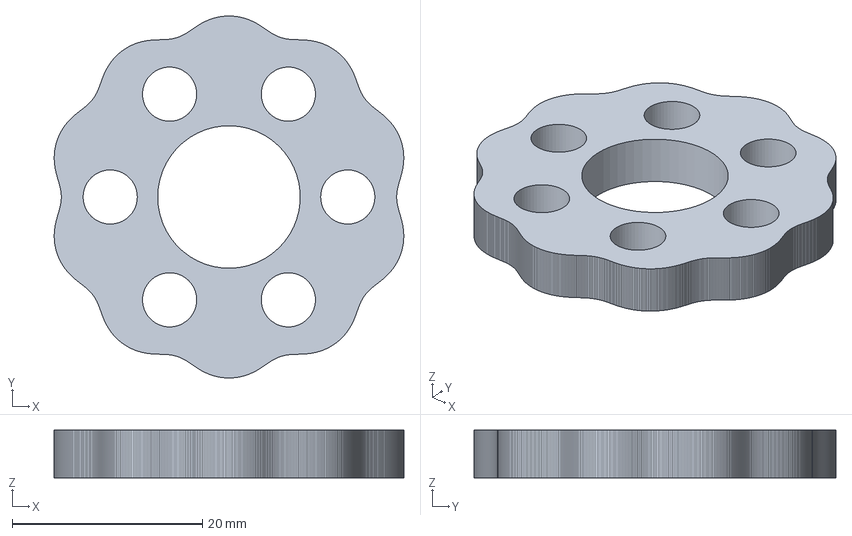
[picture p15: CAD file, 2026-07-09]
cycloidal-2stage/out/disc2.step
36.8 x 38.1 x 5.00 mm

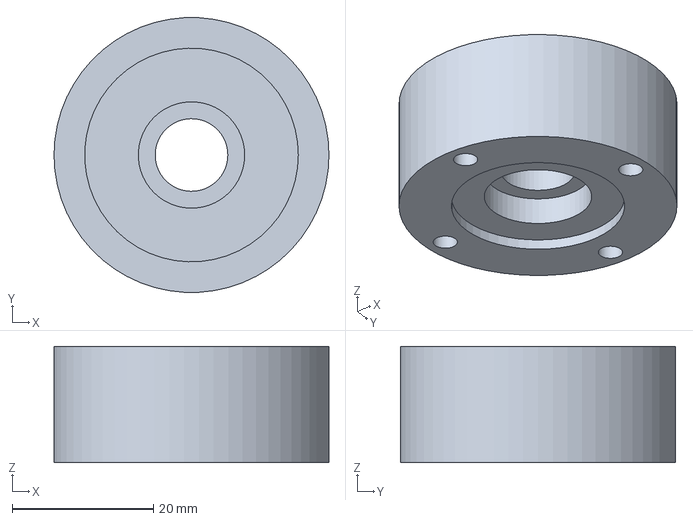
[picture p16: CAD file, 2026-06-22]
cycloidal-center/out/output_housing.step
39.0 x 38.9 x 16.5 mm

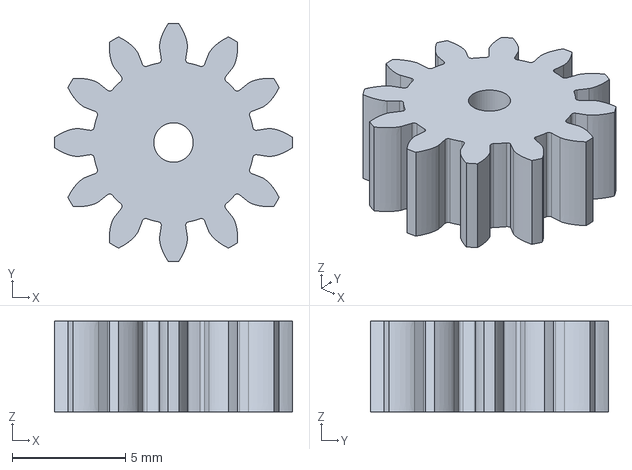
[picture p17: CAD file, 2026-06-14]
cycloidal/out/planet.step
10.5 x 10.5 x 4.00 mm

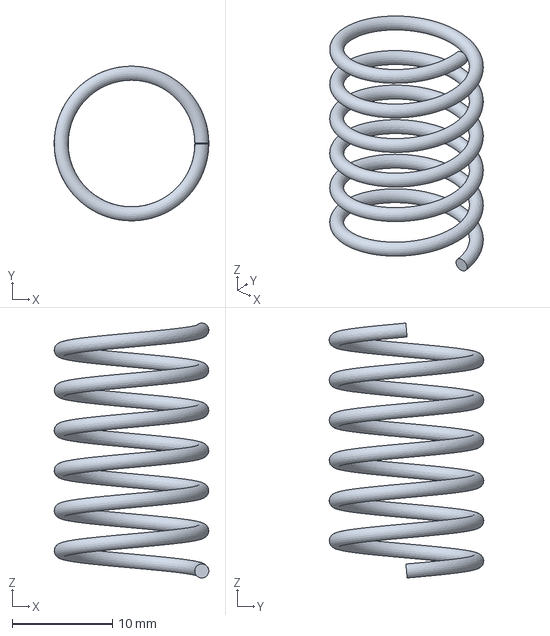
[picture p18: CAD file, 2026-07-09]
flex/out/spring.step
15.4 x 15.4 x 25.4 mm

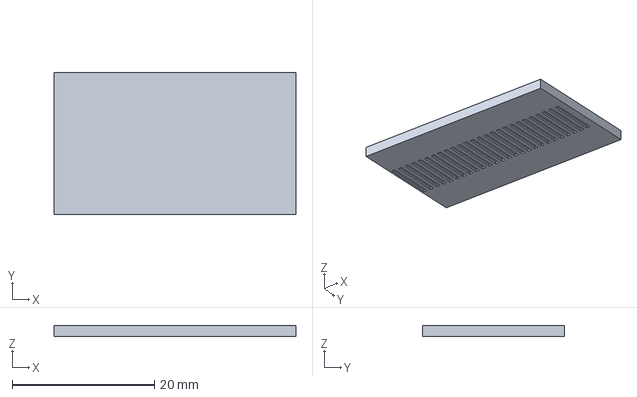
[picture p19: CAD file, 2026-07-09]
linear-rail-servo/out/slider_pcb.step
34.0 x 20.0 x 1.60 mm

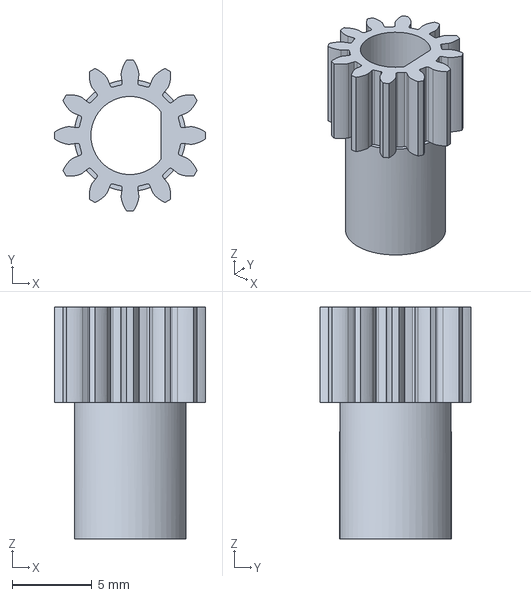
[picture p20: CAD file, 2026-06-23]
planetary-inverted/out/sun.step
9.48 x 9.48 x 14.6 mm

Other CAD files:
tendril/out/tendril.step
yzipper/out/strip_bend.step
zipchain/out/sprocket.step
cycloidal-2stage/out/central_disc.step
cycloidal-2stage/out/base.step
cycloidal-2stage/out/base.stl
cycloidal-2stage/out/central_disc.stl
cycloidal-2stage/out/disc1.step
cycloidal-2stage/out/disc1.stl
cycloidal-2stage/out/disc2.stl
cycloidal-2stage/out/eccentric.step
cycloidal-2stage/out/eccentric.stl
cycloidal-2stage/out/output_drum.step
cycloidal-2stage/out/output_drum.stl
cycloidal-2stage/out/post.step
cycloidal-2stage/out/post.stl
cycloidal-2stage/out/yoke.step
cycloidal-2stage/out/yoke.stl
cycloidal-center/out/carrier_back.step
cycloidal-center/out/carrier_back.stl
cycloidal-center/out/carrier_front.step
cycloidal-center/out/carrier_front.stl
cycloidal-center/out/disc.step
cycloidal-center/out/disc.stl
cycloidal-center/out/eccentric.step
cycloidal-center/out/eccentric.stl
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

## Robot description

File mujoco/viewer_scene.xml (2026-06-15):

<mujoco model="hybrid_viewer">
  <!-- Full integrated hybrid actuator, driven KINEMATICALLY by run.py --view.
       Translucent housing + cap show the real enclosed can; the internals animate
       at their true ratios: output 1x | carrier 10x | sun 40x | planets orbit 10x /
       spin -20x | disc orbits on the eccentric. Parts sit on the shared axial datum
       (Params.stack) so nothing interpenetrates. -->

  <compiler meshdir="../cycloidal/out" angle="degree" autolimits="true"/>
  <option gravity="0 0 0"/>

  <asset>
    <mesh name="housing" file="housing.stl" scale="0.001 0.001 0.001"/>
    <mesh name="cap" file="output_cap.stl" scale="0.001 0.001 0.001"/>
    <mesh name="planet_ring" file="planet_ring.stl" scale="0.001 0.001 0.001"/>
    <mesh name="sun" file="sun.stl" scale="0.001 0.001 0.001"/>
    <mesh name="planet" file="planet.stl" scale="0.001 0.001 0.001"/>
    <mesh name="carrier" file="carrier_eccentric.stl" scale="0.001 0.001 0.001"/>
    <mesh name="disc" file="disc.stl" scale="0.001 0.001 0.001"/>
    <mesh name="output" file="output_carrier.stl" scale="0.001 0.001 0.001"/>
    <material name="case" rgba="0.70 0.72 0.75 0.10"/>   <!-- translucent shell      -->
    <material name="ringg" rgba="0.55 0.57 0.62 1"/>
    <material name="sun" rgba="0.95 0.72 0.10 1"/>      <!-- input: bright, opaque   -->
    <material name="plan" rgba="0.20 0.80 0.40 1"/>
    <material name="carr" rgba="0.80 0.45 0.30 0.35"/>   <!-- translucent: see the sun -->
    <material name="disc" rgba="0.40 0.60 0.90 0.35"/>   <!-- translucent              -->
    <material name="out" rgba="0.25 0.55 0.90 0.55"/>
    <material name="mark" rgba="0.90 0.10 0.10 1"/>      <!-- rotation index markers   -->
  </asset>

  <worldbody>
    <light pos="0.05 -0.05 0.12" dir="-0.4 0.4 -1"/>
    <camera name="iso" pos="0.060 -0.060 0.055" xyaxes="0.7 0.7 0 -0.4 0.4 0.82"/>

    <!-- translucent enclosed can (context) -->
    <geom type="mesh" mesh="housing" material="case" contype="0" conaffinity="0"/>
    <geom type="mesh" mesh="cap" material="case" pos="0 0 0.0175" contype="0" conaffinity="0"/>

    <!-- fixed planetary ring gear -->
    <geom type="mesh" mesh="planet_ring" material="ringg" pos="0 0 0.001"/>

    <!-- sun on the motor shaft: 40x (the input). Bright + a radial marker so the
         fast spin reads through the translucent carrier/disc stacked above it. -->
    <body name="sun_body" pos="0 0 0.001">
      <joint name="joint_sun" type="hinge" axis="0 0 1"/>
      <geom type="mesh" mesh="sun" material="sun"/>
      <geom type="box" pos="0.0036 0 0.0021" size="0.0036 0.0010 0.0010" material="mark"/>
    </body>

    <!-- carrier-eccentric: planet carrier (10x); orbits planets + carries the disc -->
    <body name="planet_carrier_body" pos="0 0 0.0055">
      <joint name="joint_pcarrier" type="hinge" axis="0 0 1"/>
      <geom type="mesh" mesh="carrier" material="carr"/>
      <geom type="box" pos="0.012 0 0.0024" size="0.003 0.001 0.001" material="carr"/>

      <body name="planet0" pos="0.009 0 -0.0045"><joint name="joint_planet0" type="hinge" axis="0 0 1"/>
        <geom type="mesh" mesh="planet" material="plan"/></body>
      <body name="planet1" pos="0 0.009 -0.0045"><joint name="joint_planet1" type="hinge" axis="0 0 1"/>
        <geom type="mesh" mesh="planet" material="plan"/></body>
      <body name="planet2" pos="-0.009 0 -0.0045"><joint name="joint_planet2" type="hinge" axis="0 0 1"/>
        <geom type="mesh" mesh="planet" material="plan"/></body>
      <body name="planet3" pos="0 -0.009 -0.0045"><joint name="joint_planet3" type="hinge" axis="0 0 1"/>
        <geom type="mesh" mesh="planet" material="plan"/></body>

      <!-- cycloidal disc rides the eccentric journal (offset by E), orbits with the carrier -->
      <geom type="mesh" mesh="disc" material="disc" pos="0.0007 0 0.003"/>
    </body>

    <!-- output carrier: 1x, the slow output -->
    <body name="output_body" pos="0 0 0.014">
      <joint name="joint_out" type="hinge" axis="0 0 1"/>
      <geom type="mesh" mesh="output" material="out"/>
      <geom type="box" pos="0.010 0 0.0035" size="0.003 0.0011 0.0011" material="mark"/>
    </body>
  </worldbody>
</mujoco>

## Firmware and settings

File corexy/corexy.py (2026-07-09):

"""
Control proof for a CoreXY stage driven by cheap TT gearmotors and closed on PER-AXIS
DRAW-WIRE encoders (drawwire.py) instead of the motor shafts.

Why CoreXY makes the "precision lives in the sensor" argument inescapable:
the two fixed motors are COUPLED into Cartesian motion —
      X = (a + b)/2,   Y = (a − b)/2      (a,b = the two belt feeds)
so every belt defect (backlash, position-dependent stretch, a skipped tooth) leaks into
BOTH X and Y at the toolhead, and the long CoreXY belt path has more of all of them than a
single axis. Motor encoders are structurally blind to it. Close the loop on a load-side
sensor (a string encoder on each axis) and it all lands inside the loop and cancels.

The math also DECOUPLES the dynamics, which is why this reuses the rail-servo drive twice.
In belt coordinates p = X+Y, q = X−Y the toolhead kinetic energy splits,
      KE = ½m(Ẋ²+Ẏ²) = ½(m/2)ṗ² + ½(m/2)q̇²,
so p and q are two INDEPENDENT 1-D drives (each: motor → backlash gap ±δ → belt spring →
load mass m/2), exactly like linear-rail-servo/servo.py. The controller re-couples them:
it reads the toolhead (X,Y), runs a Cartesian PID + profile feedforward, and maps the
command back to the two motors through the CoreXY Jacobian transpose (u_a = Fx+Fy,
u_b = Fx−Fy). Feedforward is done in belt coordinates so each drive is unburdened.

  FEEDBACK MODES:
    string — read (X,Y) from the two draw-wire encoders (σ ≈ drawwire.noise_rms, ~3 µm).
             Backlash + stretch are INSIDE the loop → cancelled at the toolhead.
    shaft  — read (X,Y) from the motor encoders: X=(a_m+b_m)/2 etc. Blind to the belts →
             the toolhead traces a backlash-notched, stretch-bowed path.

Trustworthy: the qualitative belt-error cancellation, the reversal notches ≈ backlash, the
load-dependent bow from position-dependent belt stretch. First-order: lumped equal X/Y
inertia (clean p,q decoupling), smoothed friction, one belt spring per axis, no motor
electrical dynamics.

    ../.venv/bin/python corexy/corexy.py            # report + out/corexy.png
"""

from dataclasses import dataclass, field
from pathlib import Path

import numpy as np

from drawwire import DrawWireEncoder

HERE = Path(__file__).resolve().parent
OUT = HERE / "out"


@dataclass
class CoreXYParams:
    # --- moving mass / workspace ----------------------------------------------
    toolhead_mass_kg: float = 0.40     # gantry + toolhead, lumped equal in X and Y
    work_mm: float = 200.0             # square workspace side
    pulley_radius_mm: float = 6.0      # GT2 16T-ish

    # --- TT gearmotor per belt (same garbage as the rail) ----------------------
    out_stall_torque_Nm: float = 0.06
    out_noload_rpm: float = 200.0
    out_inertia: float = 4.0e-5
    f_coulomb: float = 0.10            # gearbox Coulomb, belt-referred [N]
    backlash_deg: float = 3.0          # lash at each output shaft
    cog_frac: float = 0.03
    cog_teeth: float = 12.0

    # --- belt (position-dependent stretch is the CoreXY-specific effect) -------
    belt_k0: float = 9.0e4             # stiffness at the home corner [N/m]
    belt_soften: float = 0.7           # k(x) = k0/(1 + soften·reach/work): far corner softer
    belt_damping: float = 30.0
    c_load: float = 8.0                # viscous drag on the moving mass [N·s/m]
    f_stick: float = 0.3               # Coulomb on the moving mass [N]

    # --- controller (Cartesian PID + belt-coord feedforward) -------------------
    kp: float = 8000.0
    ki: float = 5000.0
    kd: float = 150.0
    d_filt_hz: float = 30.0
    in_pos_um: float = 10.0
    control_hz: float = 1000.0
    shaft_enc_res_mm: float = 0.05

    # --- sim -------------------------------------------------------------------
    dt: float = 2.0e-4
    wire: DrawWireEncoder = field(default_factory=lambda: DrawWireEncoder(travel_mm=300.0))

    # ---- derived --------------------------------------------------------------
    @property
    def r(self):
        return self.pulley_radius_mm * 1e-3

    @property
    def work(self):
        return self.work_mm * 1e-3

    @property
    def motor_mass(self):
        return self.out_inertia / self.r ** 2

    @property
    def f_stall(self):
        return self.out_stall_torque_Nm / self.r

    @property
    def v_noload(self):
        return (self.out_noload_rpm * 2 * np.pi / 60.0) * self.r

    @property
    def backlash(self):
        return np.deg2rad(self.backlash_deg) * self.r

    @property
    def string_sigma(self):
        return self.wire.noise_rms * 1e-3   # mm -> m


def _deadband(e, d):
    return max(0.0, e - d) + min(0.0, e + d)


def simulate(pr: CoreXYParams, path, mode="string", t_end=8.0, seed=0, load=(0.0, 0.0)):
    """Integrate the two decoupled belt drives under Cartesian feedback. `path(t)->(X,Y)` [m].
    `load` is a constant external Cartesian force [N] (to expose belt stretch)."""
    rng = np.random.default_rng(seed)
    dt = pr.dt
    n = int(t_end / dt)
    ctrl_every = max(1, int(round(1.0 / (pr.control_hz * dt))))
    M_m = pr.motor_mass
    M_l = pr.toolhead_mass_kg / 2.0            # effective load mass per belt coord
    b_emf = pr.f_stall / pr.v_noload
    db, cb = pr.backlash, pr.belt_damping
    veps = 1e-4
    a_d = np.exp(-2 * np.pi * pr.d_filt_hz / pr.control_hz)
    i_max = 2 * pr.f_stall / pr.ki
    e_dead = (pr.in_pos_um * 1e-6, pr.in_pos_um * 1e-6) if mode == "string" \
        else (0.7 * pr.shaft_enc_res_mm * 1e-3,) * 2

    # belt-coordinate state: index 0 = p (=X+Y), 1 = q (=X−Y)
    X0, Y0 = path(0.0)
    xx = [X0 + Y0, X0 - Y0]                     # load-side belt coords
    xd = [0.0, 0.0]
    m = list(xx)                               # motor-side belt coords
    md = [0.0, 0.0]
    integ = [0.0, 0.0]; e_prev = [0.0, 0.0]; deriv = [0.0, 0.0]; u = [0.0, 0.0]

    out = {k: np.empty(n) for k in ("t", "X", "Y", "Xc", "Yc", "Xm", "Ym")}

    def belt_k(load_pos):
        reach = abs(load_pos)                  # softer as the belt pays out from home
        return pr.belt_k0 / (1.0 + pr.belt_soften * reach / pr.work)

    for i in range(n):
        t = i * dt
        Xc, Yc = path(t)
        # actual toolhead from the load-side belt coords
        X = 0.5 * (xx[0] + xx[1]); Y = 0.5 * (xx[0] - xx[1])

        if i % ctrl_every == 0:
            if mode == "string":               # per-axis draw-wire on the load
                Xmeas = X + rng.normal(0, pr.string_sigma)
                Ymeas = Y + rng.normal(0, pr.string_sigma)
            else:                              # motor encoders: believe X=(a_m+b_m)/2
                q = pr.shaft_enc_res_mm * 1e-3
                am = np.round(m[0] / q) * q; bm = np.round(m[1] / q) * q
                Xmeas = 0.5 * (am + bm); Ymeas = 0.5 * (am - bm)
            # Cartesian PID per axis
            u_fb = [0.0, 0.0]
            F = [0.0, 0.0]
            for ax, (err_now, meas, cmd) in enumerate(
                    ((Xc - Xmeas, Xmeas, Xc), (Yc - Ymeas, Ymeas, Yc))):
                e = err_now
                deriv[ax] = a_d * deriv[ax] + (1 - a_d) * (e - e_prev[ax]) * pr.control_hz
                e_prev[ax] = e
                if abs(e) < e_dead[ax]:
                    integ[ax] *= 0.98
                    F[ax] = pr.kd * deriv[ax] + pr.ki * integ[ax]
                else:
                    pd = pr.kp * e + pr.kd * deriv[ax]
                    if abs(pd + pr.ki * integ[ax]) < 2 * pr.f_stall:
                        integ[ax] = np.clip(integ[ax] + e / pr.control_hz, -i_max, i_max)
                    F[ax] = pd + pr.ki * integ[ax]
            Fx, Fy = F
            # belt-coordinate feedforward (unburden each drive)
            h = 1.0 / pr.control_hz
            Xp, Yp = path(t + h); Xm2, Ym2 = path(t - h)
            pr_ref = [(Xc + Yc), (Xc - Yc)]
            vref = [((Xp + Yp) - (Xm2 + Ym2)) / (2 * h), ((Xp - Yp) - (Xm2 - Ym2)) / (2 * h)]
            aref = [((Xp + Yp) - 2 * pr_ref[0] + (Xm2 + Ym2)) / (h * h),
                    ((Xp - Yp) - 2 * pr_ref[1] + (Xm2 - Ym2)) / (h * h)]
            # Jacobian transpose: motor a<-Fx+Fy (drives p), motor b<-Fx-Fy (drives q)
            u_fb = [Fx + Fy, Fx - Fy]
            for j in range(2):
                u[j] = u_fb[j] + (M_m + M_l) * aref[j] + b_emf * vref[j]

        # external Cartesian load -> belt coords
        lb = [load[0] + load[1], load[0] - load[1]]
        for j in range(2):
            cog = pr.cog_frac * pr.f_stall * np.sin(pr.cog_teeth * m[j] / pr.r)
            f_motor = np.clip(u[j], -pr.f_stall, pr.f_stall) - b_emf * md[j] + cog \
                - pr.f_coulomb * np.tanh(md[j] / veps)
            e_gap = m[j] - xx[j]
            k = belt_k(xx[j] - (X0 + Y0 if j == 0 else X0 - Y0))
            F_c = k * _deadband(e_gap, db) + (cb * (md[j] - xd[j]) if abs(e_gap) > db else 0.0)
            a_m = (f_motor - F_c) / M_m
            a_x = (F_c - pr.c_load * xd[j] - pr.f_stick * np.tanh(xd[j] / veps) - lb[j]) / M_l
            md[j] += a_m * dt; m[j] += md[j] * dt
            xd[j] += a_x * dt; xx[j] += xd[j] * dt

        out["t"][i] = t; out["Xc"][i] = Xc; out["Yc"][i] = Yc
        out["X"][i] = X; out["Y"][i] = Y
        out["Xm"][i] = 0.5 * (m[0] + m[1]); out["Ym"][i] = 0.5 * (m[0] - m[1])
    return out


# ---- paths ------------------------------------------------------------------
def circle_path(cx, cy, R, period, t0=0.4):
    def f(t):
        if t < t0:
            return cx + R, cy
        ph = 2 * np.pi * (t - t0) / period
        return cx + R * np.cos(ph), cy + R * np.sin(ph)
    return f


def square_path(cx, cy, half, period, t0=0.4):
    pts = [(cx + half, cy + half), (cx - half, cy + half),
           (cx - half, cy - half), (cx + half, cy - half)]

    def f(t):
        if t < t0:
            return pts[0]
        ph = ((t - t0) / period) % 1.0
        seg = int(ph * 4) % 4
        fr = ph * 4 - int(ph * 4)
        a = pts[seg]; b = pts[(seg + 1) % 4]
        return a[0] + (b[0] - a[0]) * fr, a[1] + (b[1] - a[1]) * fr
    return f


CIRCLE_PERIOD = 12.0                       # slow enough for the weak motor (no saturation)


def _trace_error(pr, path, mode, t_end, **kw):
    r = simulate(pr, path, mode, t_end, **kw)
    keep = r["t"] > CIRCLE_PERIOD * 0.6
    ex = r["X"][keep] - r["Xc"][keep]; ey = r["Y"][keep] - r["Yc"][keep]
    return np.hypot(ex, ey)


def hold_droop(pr, mode, Xs, cy, load):
    """Hold at each X under a constant Cartesian `load`; return the settled position error
    [m]. Reveals position-dependent belt stretch: the shaft loop droops (and the droop
    varies with position as the belt softens); the string loop holds regardless."""
    errs = []
    for X in Xs:
        r = simulate(pr, lambda t: (X, cy), mode, 4.5, load=load)   # settle fully under load
        k = r["t"] > 4.0
        errs.append(np.hypot(np.mean(r["X"][k]) - X, np.mean(r["Y"][k]) - cy))
    return np.array(errs)


def report(pr: CoreXYParams | None = None):
    pr = pr or CoreXYParams()
    print("\n" + "=" * 70)
    print("  CoreXY STAGE  —  TT gearmotors, loop on draw-wire scales vs motor shafts")
    print("=" * 70)
    print(f"  toolhead {pr.toolhead_mass_kg*1e3:.0f} g, workspace {pr.work_mm:.0f}² mm, "
          f"pulley Ø{2*pr.pulley_radius_mm:.0f} mm")
    print(f"  per-belt backlash {pr.backlash*1e6:.0f} µm, motor f_stall {pr.f_stall:.1f} N")
    print(f"  draw-wire scale noise σ = {pr.string_sigma*1e6:.1f} µm  "
          f"(shaft encoder LSB {pr.shaft_enc_res_mm*1e3:.0f} µm)")
    print("-" * 70)
    cx = cy = pr.work_mm / 2 * 1e-3
    cir = circle_path(cx, cy, 0.06, period=CIRCLE_PERIOD)
    Xs = np.linspace(cx - 0.06, cx + 0.06, 7)
    for mode in ("shaft", "string"):
        e = _trace_error(pr, cir, mode, t_end=2.5 * CIRCLE_PERIOD) * 1e6
        droop = hold_droop(pr, mode, Xs, cy, load=(0.0, 5.0)) * 1e6
        print(f"  loop on {mode:>6}:  circle RMS {np.sqrt(np.mean(e**2)):6.1f} µm "
              f"(peak {np.max(e):6.1f})   | 5 N hold droop {np.mean(droop):6.1f} µm")
    print("-" * 70)
    print("  Backlash notches the traced circle and belt stretch droops it under load —")
    print("  both only when the loop closes on the motor shaft, not the toolhead.")
    print("=" * 70 + "\n")
    return pr


def render(pr: CoreXYParams | None = None):
    pr = pr or CoreXYParams()
    import matplotlib
    matplotlib.use("Agg")
    import matplotlib.pyplot as plt

    cx = cy = pr.work_mm / 2 * 1e-3
    R = 0.06
    fig, ax = plt.subplots(2, 2, figsize=(12.5, 10))

    # (a) traced circle: commanded vs motor-loop vs string-loop
    cir = circle_path(cx, cy, R, period=CIRCLE_PERIOD)
    tend = 2.5 * CIRCLE_PERIOD
    rs = simulate(pr, cir, "shaft", tend)
    rr = simulate(pr, cir, "string", tend)
    keep = rs["t"] > CIRCLE_PERIOD * 0.6
    ax[0, 0].plot((rs["Xc"][keep]) * 1e3, (rs["Yc"][keep]) * 1e3, "k--", lw=0.8, label="commanded")
    ax[0, 0].plot(rs["X"][keep] * 1e3, rs["Y"][keep] * 1e3, color="C3", lw=1.3, label="shaft loop")
    ax[0, 0].plot(rr["X"][keep] * 1e3, rr["Y"][keep] * 1e3, color="C0", lw=1.3, label="string loop")
    ax[0, 0].set_aspect("equal"); ax[0, 0].set_title("(a) traced circle: shaft loop notches on backlash")
    ax[0, 0].set_xlabel("X  [mm]"); ax[0, 0].set_ylabel("Y  [mm]")
    ax[0, 0].legend(fontsize=8, loc="upper right"); ax[0, 0].grid(alpha=0.3)

    # (b) radial error vs angle around the circle
    def radial(r):
        k = r["t"] > CIRCLE_PERIOD * 0.6
        ang = np.arctan2(r["Y"][k] - cy, r["X"][k] - cx)
        rad = np.hypot(r["X"][k] - cx, r["Y"][k] - cy)
        o = np.argsort(ang)
        return np.degrees(ang[o]), (rad[o] - R) * 1e6
    a1, e1 = radial(rs); a2, e2 = radial(rr)
    ax[0, 1].plot(a1, e1, color="C3", lw=1.0, label="shaft loop")
    ax[0, 1].plot(a2, e2, color="C0", lw=1.0, label="string loop")
    ax[0, 1].axhline(0, color="k", lw=0.6)
    ax[0, 1].set_title("(b) radial error vs angle — notches where a belt reverses")
    ax[0, 1].set_xlabel("angle around circle  [deg]"); ax[0, 1].set_ylabel("radial error  [µm]")
    ax[0, 1].legend(fontsize=8); ax[0, 1].grid(alpha=0.3)

    # (c) position-dependent belt stretch: hold across X under a 5 N Y-load
    Xs = np.linspace(cx - 0.06, cx + 0.06, 9)
    dh = hold_droop(pr, "shaft", Xs, cy, load=(0.0, 5.0)) * 1e6
    dr = hold_droop(pr, "string", Xs, cy, load=(0.0, 5.0)) * 1e6
    ax[1, 0].plot(Xs * 1e3, dh, "o-", color="C3", ms=4, label="shaft loop")
    ax[1, 0].plot(Xs * 1e3, dr, "o-", color="C0", ms=4, label="string loop")
    ax[1, 0].set_title("(c) hold under 5 N load: shaft droops (belt stretch), string holds")
    ax[1, 0].set_xlabel("toolhead X  [mm]"); ax[1, 0].set_ylabel("position error  [µm]")
    ax[1, 0].legend(fontsize=8); ax[1, 0].grid(alpha=0.3)

    # (d) error summary bars: backlash (circle, reuse a's runs) + stretch (load hold)
    def rms(r):
        k = r["t"] > CIRCLE_PERIOD * 0.6
        return np.sqrt(np.mean((np.hypot(r["X"][k] - r["Xc"][k], r["Y"][k] - r["Yc"][k]))**2)) * 1e6
    labels = ["circle\ntrace", "5 N\nload hold"]
    esh = [rms(rs), np.mean(dh)]
    est = [rms(rr), np.mean(dr)]
    xs = np.arange(len(labels)); w = 0.36
    b1 = ax[1, 1].bar(xs - w / 2, esh, w, color="C3", label="shaft loop")
    b2 = ax[1, 1].bar(xs + w / 2, est, w, color="C0", label="string loop")
    for bars in (b1, b2):
        for r in bars:
            ax[1, 1].annotate(f"{r.get_height():.0f}", (r.get_x() + r.get_width() / 2, r.get_height()),
                              ha="center", va="bottom", fontsize=8)
    ax[1, 1].axhline(pr.string_sigma * 1e6, color="C0", ls="--", lw=0.8, label="scale noise")
    ax[1, 1].axhline(pr.backlash * 1e6, color="C3", ls=":", lw=0.8, label="1 backlash")
    ax[1, 1].set_yscale("log")
    ax[1, 1].set_xticks(xs); ax[1, 1].set_xticklabels(labels, fontsize=9)
    ax[1, 1].set_title("(d) RMS toolhead error — string beats shaft on both")
    ax[1, 1].set_ylabel("error  [µm]")
    ax[1, 1].legend(fontsize=8, loc="center right"); ax[1, 1].grid(alpha=0.3, which="both", axis="y")

    fig.suptitle("CoreXY on cheap TT motors — the loop must close on the toolhead (draw-wire), "
                 "not the motors", fontsize=13)
    fig.tight_layout(rect=(0, 0, 1, 0.97))
    OUT.mkdir(exist_ok=True)
    fig.savefig(OUT / "corexy.png", dpi=120)
    print(f"  wrote {OUT/'corexy.png'}")


if __name__ == "__main__":
    pr = report()
    render(pr)

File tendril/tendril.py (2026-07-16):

"""
Kinematics + statics of a SERVO-DRIVEN, TENDON-PULLED SEGMENTED TENDRIL — the buildable 1-DOF
gripper finger. Rigid TPU VERTEBRAE are joined by a thin flexible SPINE; one MG996R hobby servo
(mounted with its shaft ACROSS the finger axis, so the horn spins in the bending plane) reels an
antagonistic string loop straight down the axis — no 90° cable bend.

Why segmented (vs one solid flexing beam):
    bending concentrates at the thin spine sections between rigid vertebrae, so the finger is a
    string of discrete flexure hinges — predictable, and it maps 1:1 onto the sim's hinge chain.
    The rigid vertebrae also house the tendon channels at a generous CONSTANT offset d, which
    dodges the thin-tip-vs-fat-channel conflict of a tapered solid beam.

Why one servo drives a clean 1-DOF bend:
    the two strings sit at ±d from the neutral (spine) axis. Pulling one side by ΔL bends every
    joint toward it; the other side lengthens by the same ΔL — exactly what the horn pays out. The
    horn spins in the bending plane with the strings tangent to it, so take-up is ΔL = r_h·ψ (a
    little capstan) and the antagonistic pair is kinematically self-consistent: one ψ ↔ one bend.

Model — discrete flexure-jointed spine:
    joint i   thin spine flexure, length = gap, section w_spine×t_spine
              rotational stiffness  k = E·I_spine/gap ,  I_spine = w_spine·t_spine³/12
    moment    each joint sees T·d from the tendon → bends Δθ = T·d/k
    the SAME two sums drive everything (as the continuous J1/J2 did, now discrete):
        θ  = T·J1 ,  J1 = Σ d/k = N_j·d/k          (tip angle)
        ΔL = T·J2 ,  J2 = Σ d²/k = N_j·d²/k         (tendon take-up)
    drive     ΔL = r_h·ψ  →  T = r_h·ψ/J2  →  dθ/dψ = r_h/d_eff,  d_eff ≡ J2/J1 = d (constant offset)

Forces:  isometric tip-push F = surplus_T/(d|tip|/dΔL) [virtual work];  wrap/contact F ≈ T·θ [capstan].
Trustworthy: transmission, the discrete curl shape, tension↔servo-torque, the wrap force, the
vertebra-collision curl limit. First-order: linear TPU spine, rigid vertebrae, straight tendon in
the vertebrae. E_tpu is the dominant uncertainty — everything scales ∝ 1/E.

    ../.venv/bin/python tendril/tendril.py         # report + out/tendril.png
"""

from dataclasses import dataclass
from math import pi
from pathlib import Path

import numpy as np

HERE = Path(__file__).resolve().parent
OUT = HERE / "out"
KGF_CM = 0.0980665                 # 1 kgf·cm in N·m


@dataclass
class TendrilParams:
    # --- segmented TPU finger: rigid vertebrae + thin flexible spine ---
    n_vert: int = 9                # number of rigid vertebrae
    seg_len_mm: float = 7.0        # rigid vertebra length (along the finger axis)
    gap_mm: float = 3.0            # flexure gap between vertebrae (only the spine spans it)
    spine_t_mm: float = 3.0        # spine thickness (bending direction) — the compliant element
    spine_w_mm: float = 6.0        # spine width
    seg_t_mm: float = 8.0          # vertebra thickness (bending dir) — houses the channels
    seg_w_mm: float = 12.0         # vertebra width
    d_off_mm: float = 2.5          # tendon channel offset from the neutral (spine) axis — CONSTANT
    E_tpu_MPa: float = 25.0        # TPU flexural modulus — DOMINANT uncertainty (only the spine flexes)

    # --- single hobby servo, shaft ACROSS the axis, antagonistic string pair ---
    horn_r_mm: float = 8.0         # string hole radius on the horn (in-plane lever → take-up r·sinψ)
    servo_stall_kgcm: float = 10.0 # MG996R ~10 kgf·cm @6V
    servo_travel_deg: float = 90.0 # ± horn range
    string_break_N: float = 200.0  # Dyneema ~0.5 mm
    tpu_pullout_N: float = 30.0    # practical channel tear-out limit (the real tension ceiling)

    # ---- SI helpers -----------------------------------------------------------
    @property
    def n_joints(self): return self.n_vert - 1
    @property
    def length_mm(self):
        return self.n_vert * self.seg_len_mm + self.n_joints * self.gap_mm
    @property
    def L(self): return self.length_mm * 1e-3
    @property
    def d(self): return self.d_off_mm * 1e-3
    @property
    def r_h(self): return self.horn_r_mm * 1e-3
    @property
    def E(self): return self.E_tpu_MPa * 1e6
    @property
    def tau_stall(self): return self.servo_stall_kgcm * KGF_CM
    @property
    def psi_max(self): return np.deg2rad(self.servo_travel_deg)
    @property
    def T_max(self): return self.tau_stall / self.r_h
    @property
    def T_cap(self):
        """Practical tension ceiling: whichever of servo / string / TPU-channel gives out first."""
        return min(self.T_max, self.string_break_N, self.tpu_pullout_N)

    # ---- spine flexure stiffness ----------------------------------------------
    @property
    def I_spine(self):
        return self.spine_w_mm * 1e-3 * (self.spine_t_mm * 1e-3) ** 3 / 12.0
    @property
    def k_joint(self):
        """Rotational stiffness of ONE spine flexure [N·m/rad]."""
        return self.E * self.I_spine / (self.gap_mm * 1e-3)
    @property
    def EI_vert(self):
        return self.E * self.seg_w_mm * 1e-3 * (self.seg_t_mm * 1e-3) ** 3 / 12.0

    # ---- the two (now discrete) compliance sums --------------------------------
    @property
    def J1(self): return self.n_joints * self.d / self.k_joint          # θ  = T·J1
    @property
    def J2(self): return self.n_joints * self.d ** 2 / self.k_joint     # ΔL = T·J2
    @property
    def d_eff(self): return self.J2 / self.J1                           # = d (constant offset)
    @property
    def ratio(self):
        """Small-signal transmission dθ/dψ AT NEUTRAL = r_h/d_eff. The horn is an in-plane lever
        (string tied to a hole), so take-up is r_h·sinψ → the bend SATURATES toward full travel."""
        return self.r_h / self.d_eff
    @property
    def joint_angle_max(self):
        """Per-joint bend at which adjacent vertebrae collide on the concave edge (hard stop)."""
        return (self.gap_mm * 1e-3) / (self.seg_t_mm * 1e-3 / 2.0)

    # ---- forward map: servo angle → tension → curl -----------------------------
    def delta_L(self, psi):
        """Tendon take-up [m] from the in-plane horn lever: string tied at r_h, so ΔL = r_h·sinψ
        (signed). Saturates at r_h as ψ→90° — the geometric price of no 90° cable bend."""
        return self.r_h * np.sin(psi)

    def tension_for(self, psi):
        """Tendon tension to hold horn angle ψ: |ΔL| = T·J2."""
        return abs(self.delta_L(psi)) / self.J2

    def joint_angle(self, psi):
        """Signed per-joint bend Δθ = (ΔL/d)/N_j  (θ_total = T·J1 = ΔL/d)."""
        return (self.delta_L(psi) / self.d) / self.n_joints
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

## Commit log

2026-06-10 Miniature cycloidal actuator: parametric CAD + MuJoCo sim pipeline
    Simulate-first robot actuator R&D. v1 is a 10:1 single-stage cycloidal
    drive for the Goolsky 2204 1400KV outrunner.
    - cycloidal/drive.py: parametric build123d generator with a feasibility
    validator (catches radial-clearance conflicts before meshing geometry);
    exports watertight STL + STEP for disc/ring/eccentric/carrier.
    - mujoco/: CAD ratio -> actuator spec -> drivable testbench. Single source
    of truth so geometry and sim never drift. Headless sizing scenarios +
    a real-time kinematic viewer demoing the 10:1 reduction.
    [assembly.step, carrier.step, carrier.stl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]
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2026-06-10 Encode contact strategy (rolling vs sliding) as parameters
    The efficiency-critical choice is now a Param, not a README note:
    - pin_mode "fixed"|"rolling": rolling = free-spinning dowel in an oversized
    pocket (rolling lobe contact, the biggest single efficiency lever).
    Optional hardened sleeve via pin_core_dia < pin_dia.
    - out_mode "printed"|"steel"|"bushing": printed integral pins -> pressed
    steel pins -> core + rotating bushing. Carrier geometry switches between
    integral pins and press-fit holes accordingly.
    - validator: sleeve/bushing wall-thickness checks + a printed contact-strategy
    summary (ROLLING/SLIDING per interface).
    - hardware_bom(): lists the non-printed parts for the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
    [assembly.step, carrier.step, carrier.stl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]
2026-06-10 Add Layer B v0 efficiency model; close the Layer A<->B loop
    cycloidal/efficiency.py: first-order analytical efficiency model.
    - Predicts η per contact strategy from friction coefficients (calibration-
    pending coefficients; relative ranking robust). printed ~65%, default
    rolling-pins+steel ~86%, all-needle ~93%.
    - Needle-bearing fit sweep: which real bearings drop in vs force the drive
    to grow (Ø2.5 loose-needle fits as-is; HK drawn-cups push it to Ø44-48).
    - params_to_contacts() maps the CAD's pin_mode/out_mode onto contact types.
    run.py now imports predict_params() and sets the sim η from the geometry
    model instead of a hand-typed 0.70 -> peak torque 0.62 -> 0.76 N.m.
    Finding: r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
2026-06-10 Torque-based (load-dependent) efficiency model in the sim
    Efficiency is no longer flat: a constant no-load drag must be overcome
    before useful torque appears, so η rises from 0 toward η∞ with load.
    - efficiency.py: eta_at_load(T, eta_inf, drag) = eta_inf*T/(T+drag);
    drag_out(p) = input drag * ratio. predict() now documented as η∞.
    - actuator.py: ActuatorSpec carries eta_inf + drag_out; peak torque is
    net of drag; report() prints the η-vs-load curve.
    - run.py: gear = η∞, joint frictionloss = drag -> the sim REALIZES the
    curve. New Scenario D measures η vs load from sim power balance; the
    measured η tracks the model (61/71/78/82% at 0.05/0.1/0.2/0.4 N.m).
    Operating η to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
    [assembly.step, carrier.step, disc.step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]
2026-06-11 Back-EMF motor model + torque-speed curve
    The motor is now driven by throttle (voltage), not raw current. Back-EMF
    (Ke=Kt) opposes the bus voltage, so available current is (throttle*V -
    Ke*omega)/R, clamped to the rating. Yields the real two-regime envelope:
    current-limited (flat ~0.74 N.m) below ~995 rpm, then voltage-limited
    droop to zero at the 1554 rpm no-load speed.
    - actuator.py MotorSpec: ke, stall_current, corner_speed, current_at();
    ActuatorSpec.torque_at_speed(); report() prints the torque-speed curve.
    - run.py: drive_voltage() helper; Scenario B now full-throttle (settles
    at a capped speed, no freewheel); new Scenario E traces the torque-speed
    curve from a real sim spin-up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
    [assembly.step, carrier.step, disc.step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]
2026-06-11 Docs: reconcile README with load-dependent η + back-EMF
    Final consistency pass for the pause point:
    - Caveats: replace the stale "η=0.70 assumption / no back-EMF yet" with
    the current state (η model-derived but calibration-pending; electrical
    model steady-state, no L/FOC; continuous torque still a thermal guess).
    - Layer A description + "how it's wired" now mention the load-dependent
    efficiency and the back-EMF torque-speed curve.
2026-06-14 Hybrid planetary + cycloidal drive (concentric 40:1)
    Add a planetary input stage ahead of the cycloidal, fully concentric:
    motor -> planetary 4:1 (12/12/36, 4 planets) -> cycloidal eccentric -> 10:1
    -> output = 40:1 total. Cycloidal stays last for low output backlash.
    - cycloidal/gears.py: involute planetary gears — bd_warehouse SpurGear for
    sun/planet, custom involute INTERNAL ring gear (no library has one).
    - drive.py: planetary Params + derived ratios (p.ratio now = total), feasibility
    checks (spacing, planet collision, ring-fits-housing, sun-clears-shaft), and
    sun/planet/ring/carrier part builders + STEP/STL exports (8 parts).
    - efficiency.py: two-stage eta (planetary x cycloida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
    [assembly.step, carrier.step, disc.step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]
2026-06-14 Integrated, printable actuator: module-0.75 gears + enclosed case
    Rework the loose kinematic parts into one enclosed, supported assembly that
    prints and mates (parts no longer float/interpenetrate).
    - Single axial datum: Params.stack() places every part on z=0 at the motor face,
    shared by the build() assembly AND the viewer so CAD and animation can't drift.
    - housing: integrated case — motor-mount flange + STEPPED cavity (wide for the
    planetary ring, narrow for the cyclo disc) + cyclo ring-pin pockets + cap bolts.
    - output_cap: 688 output-support bearing pocket + hub through-hole + bolts.
    - output_carrier: grows a Ø8 hub = the output shaft, ridden by the cap bearing.
    - carrier_eccent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
    [carrier.step, carrier.stl, carrier_eccentric.step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]
2026-06-15 Matrix muscle: SMA cell -> recruitment bundle -> crosstalk sheet
    New muscle/ thread: an actuator built from many dumb SMA contractile cells
    whose coordinated recruitment is the control problem (the sarcomere/motor-unit
    model). Spec-as-code mirroring mujoco/actuator.py, anchored to real Flexinol-90
    (0.006") datasheet numbers.
    - cell.py: SMACellSpec — force/stroke/power of one wire; size_for() packages
    parallel (force) x series (stroke); matrix_budget() for a sheet.
    - bundle.py: ThermalCell (first-order thermal, OFF/PULSE/HOLD modes) + Bundle.
    Demonstrates contract/hold/release (holding is powered, no latch),
    linear recruitment summation, and PWM-hol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
2026-06-15 Viewer: translucent can, rotation markers, live speed control
    Make the enclosed actuator readable while it animates: translucent housing/
    cap/carrier/disc so the bright opaque sun (the input) shows through, plus red
    index markers on sun/carrier/output to read the true ratios at a glance.
    run.py --view gains live speed control: up/down arrows scale 1.5x, SPACE pause,
    R reset; default 0.10 rev/s with CLI override (--view 0.05).
    [viewer_scene.xml]
2026-06-15 Standalone single-stage planetary reducer for a 2204 drone motor
    Pull the planetary stage out of the hybrid compound as its own product: a
    single-stage 4:1 reducer (sun in / 4 planets / fixed ring / carrier out,
    12/12/36 teeth, module 0.75) sized for a high-RPM hobby BLDC. Reuses the proven
    involute generator in cycloidal/gears.py; the compound code is untouched.
    - planetary/reducer.py: ReducerParams + validate() (8 checks, all pass) + build().
    6 printable parts (housing with motor mount + ring seat, press-in ring, sun,
    planet x4, carrier with Ø8 output hub, cap with 688 pocket). Motor shaft is on
    the mount side, so the sun couples straight through the flange.
    - planetary/out/: STEP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
    [cap.step, cap.stl, carrier.step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]
2026-06-15 Planetary reducer: kinematic MuJoCo viewer
    Standalone viewer for the single-stage reducer (no compound deps). Drives every
    joint at its true 4:1 ratio: output/carrier 1x | sun 4x (input) | planets orbit
    1x with the carrier and spin -3x about their pins (ring-fixed kinematics). Live
    speed control (up/down scale, SPACE pause, R reset) mirroring mujoco/run.py.
    .venv/bin/python planetary/sim.py [out_rev_per_s]
    Translucent housing/cap + bright sun + red index markers; parts on reducer.py's
    axial datum so nothing interpenetrates. Verified: compiles, drives, renders.
2026-06-16 Planetary reducer: press-fit sun, integrated ring, NEMA-17 output
    Iterate the standalone reducer on real-fit feedback:
    - Sun grip: press fit (no setscrew, which wasted radial space). Gear + short
    press collar; bore = shaft - 2*interference. Optional D-flat param retained.
    - Ring gear is BUILT INTO the housing (carve the toothed-bore negative at the
    gear plane); dropped the separate ring part. Single watertight housing.
    - Motor mount: 4 countersunk M3 flat-heads = a 16 mm pair + a 19 mm pair; motor
    bolts underneath, screws drop through the ring bore from the top. Bumped gear
    module 0.75->0.9 so the mount-head circle clears the ring bore (case Ø40->45.6,
    ratio unchanged). Opened th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
    [cap.step, cap.stl, carrier.step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]
2026-06-22 Planetary reducer: two-plate cage + straddle input bearing
    Carrier is now two plates bolted by the planet journal screws (M2.5 axle
    doubles as the cage clamp); planets ride integral journal bosses. Adds a
    big Ø25-bore input bearing (6705) recessed low so the motor bolts pass
    inside its bore, plus a motor-can pilot recess and a longer sun press
    collar. Output keeps the NEMA-17 face + Ø5 D-shaft.
    [cap.step, carrier_bottom.step, carrier_bottom.stl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]
2026-06-22 Centre-output cycloidal + repo Makefile
    Standalone 10:1 straddle-carrier cycloidal whose output carries a moment
    load: two-part pin carrier bolted by the output rollers, supported both
    ends, nested 7x13 + 30x37 bearings (reduction path decoupled from load
    path), NEMA-17 input mount, kinematic sim + viewer. Adds a repo-root
    Makefile with build/sim targets for each drive.
    [assembly.step, assembly_full.step, carrier_back.step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]
2026-06-22 Inverted carrier-out planetary: NEMA-17 in/out, 5:1
    Re-derived from the SweepDynamics 4:1 micro planetary (12/18/48 gears,
    module ~0.677, Ø42 envelope, 7x13 + 30x37 bearing kit) and inverted from
    body-output to carrier-output: ring fixed in the housing, the two-plate
    carrier becomes the output shaft (ratio gains +1 -> 5:1, same sense as
    the sun). NEMA-17 stepper press-fits the sun on its Ø5 shaft; the output
    cap presents a NEMA-17 face (31mm M3 + Ø22 boss + Ø5 shaft) so a second
    identical stage bolts straight on. Output rides the big 30x37 for real
    overhung capacity.
    Carrier cage bolts together on 3 standoff posts in the gaps between the
    planets (extra Ø5x10 rollers as spacers + their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
    [cap.step, cap.stl, carrier_bottom.step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]
2026-06-22 Inverted planetary: integral standoff posts in carrier_bottom
    Build the 3 cage standoff posts directly into carrier_bottom as printed
    bosses (cage_post_dia, rising the roller_len plate gap to the top-hub
    underside) instead of separate rollers; the screw clearance bores through
    plate+post and threads into the top hub. Only the 3 planet axles stay as
    off-shelf Ø5x10 rollers. Adds a post-wall-over-screw check (0.75 mm);
    posts still clear the planet tips by 0.88 mm. All checks pass.
    [cap.step, carrier_bottom.step, carrier_bottom.stl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]
2026-06-22 Inverted planetary: 3-part case, bearing-loaded output, captive nuts
    Split the housing into a separate NEMA-17 `base` plate + `body`: the stepper
    and 7x13 mount to the base (motor screws accessible, bearing drops in) and the
    body OD is widened to the full NEMA plate width (Ø50.7) so the 4 long M3
    through-bolts have room and clear the ring backing. base+body+cap clamp into
    captive M3 nuts in the cap (vendor scheme, no printed case threads).
    carrier_top now rides the 30x37 on a Ø32.5 LAND that seats the inner race and
    lifts the broad carrier face 0.25 mm off the housing top, so the bearing (not a
    rubbing face) carries the carrier. The 6 cage screws thread into captive M3 nuts
    in carrier_top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
    [base.step, base.stl, body.stl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]
2026-06-22 Inverted planetary: trim stack to M3x20 case hardware
    Bring the body height down from 24.5 to 20.0 mm so a stock M3x20 through-bolt
    fully engages the cap captive nut: gear face 9.5->6.0 mm (planet rollers
    Ø5x10->Ø5x6.5, cut from stock), base plate 8->7 mm. Adds a validator check
    that the M3x<case_bolt_len> bolt reaches the nut without bottoming. Also
    switches carrier_bottom to 90° flat-head countersinks (was counterbores).
    [base.step, base.stl, body.stl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]
2026-06-23 Inverted planetary: fix sun-gear plane, add base->body register
    Fix a real bug: sun_journal_h was a fixed 5 mm, so the sun gear landed 2.5 mm
    BELOW the planet plane (meshing on half the face and hanging into the base).
    Make it derived (gear_z - in_bearing_floor_z) so the gear is coplanar with the
    planets and the journal spans the full 7x13; add validator checks for both.
    The 7x13 lower bearing seats in the `base` (Ø13 pocket, race on a ledge). Add a
    tongue-and-groove register so the base locates concentrically in the body:
    an annular tongue on the base top, between the carrier cavity and the through-
    bolts, into a matching groove in the body bottom.
    All 7 parts valid; validate() all pass.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
    [base.step, base.stl, body.stl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]
2026-06-23 Inverted planetary: straddle the carrier on two 30x37 bearings
    The body is static, so the carrier's INPUT end should ride in a bearing too
    (it was cantilevered off the single output 30x37). Rework carrier_bottom from
    a thin plate into a Ø30 HUB that rides a LOWER 30x37 seated in the base, with
    the sun's 7x13 NESTED inside the hub (8.5 mm wall) — mirroring the output end
    and the cycloidal-center pattern. Carrier is now a true straddle: lower 30x37
    in the base, upper 30x37 in the cap, sun on the nested 7x13 (3 bearings).
    Cage screws now run from the hub bottom up into the carrier_top captive nuts
    (countersunk at the hub bottom, driven before the base + bearings go on). base
    holds the lower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
    [base.step, base.stl, body.stl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]
2026-06-23 Inverted planetary: drop the base register (it undercut the bearing pocket)
    The base->body tongue register was added back when the base only held the tiny
    Ø13 7x13. Now that the base holds the Ø37 lower 30x37, the tongue (r16.1)
    overhung the Ø37 pocket (r18.5) by 2.35 mm — an undercut that traps the bearing
    so it can't be dropped in. The base top is too crowded for a clean concentric
    ring (Ø37 pocket + bolts + NEMA countersink heads reaching r24.9 at the corners),
    so remove the register entirely: the pocket now opens at the base top and the 4
    common through-bolts locate base/body/cap. Replace the register check with one
    that asserts the pocket opens at the top.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
    [base.step, base.stl, body.stl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]
2026-06-23 Inverted planetary: symmetric input end + clean ring bore
    Make the input end the MIRROR of the output end: carrier_bottom is now a Ø30
    journal -> Ø32.5 land (seats the lower 30x37 inner race) -> broad face clears
    the base by 0.25 mm -> Ø30 hub to the gear plane, exactly like carrier_top.
    The base bearing pocket mirrors the cap (Ø37 opens at the top face, bearing
    recessed with a cap_t-like floor below), so the same 30x37 seats in the base
    the way it seats in the cap. flange_t 7->8 for floor symmetry.
    Open the ring bore past the tooth tips (carrier_bore_clear_r = max(hub+clear,
    ring_inner_tip+0.3)) so there are no inward ridges at the planet-gear edges —
    the body is just the gear ring b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
    [base.step, base.stl, body.stl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]
2026-06-23 Inverted planetary: planets ride directly on M3 cage screws (no Ø5 rollers)
    Drop the Ø5 alu-roller planet axles (metal inserts not on hand) — bore the
    planets Ø3.3 so they run directly on the M3 cage screws, which already serve as
    both the planet axle and the cage clamp. roller_dia 5->3 (= the M3 shank);
    the 3 integral standoff posts still set the plate gap, so nothing pinches. The
    smaller bore also leaves more planet rim (3.6 mm). Hardware note + report
    updated; planet validation labels reworded.
    [base.step, cap.step, carrier_bottom.step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]
2026-06-23 Inverted planetary: D-shaft on the sun bore and the output shaft
    The sun now bores a press-fit D (shaft_flat_depth=0.5) to match a NEMA-17
    stepper's D-cut Ø5 shaft — interference on the round part for grip, the flat
    for positive anti-rotation. Enable the output shaft D-flat too
    (out_shaft_flat_depth 0->0.5) so a chained second stage keys to it the same
    way its sun keys to the stepper. Report notes the flats.
    [base.step, cap.step, carrier_bottom.step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]
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2026-07-07 Add piezo-hydraulic linear actuator sizing model + Makefile targets
    First linear actuator in the repo (linear/actuator.py): a first-order
    parametric model of a piezo-stack piston-pump array feeding a hydraulic
    cylinder, at robot-joint scale. Exposes the three design levers — valve
    diodicity (etched fluidic-diode vs flap check-valve), dead-volume/
    entrained-air compressibility, and output piston area as the fluidic
    gear ratio — and renders the F-v envelope, pump P-Q curve, and two
    sensitivity sweeps. Defaults: ~9.7 kN stall, ~29 mm/s no-load, ~71 W.
    Also wires 'make motor', 'make motor-curves', and 'make linear' targets.
    [actuator.py]
2026-07-09 Add two-stage compound-differential cycloidal drive + sim
    One disc per stage on a shared eccentric (Blagojevic); compound differential
    u = z1(z2+1)/(z1-z2) = 121:1. Body-output drum straddled on two bearings by an
    external grounded yoke (base + posts + far carrier). 8 watertight parts, 16 checks,
    kinematic MuJoCo viewer (make cycloidal-2stage / sim-cycloidal-2stage).
    [base.step, base.stl, central_disc.step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]
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2026-07-09 Add linear rail servo: crappy TT gearmotor + capacitive vernier scale
    Experiment in reaching precision from the cheapest components by putting it in the
    SENSOR, not the actuator. A digital-caliper-style capacitive vernier scale (two tracks
    P1/P2 beating to an absolute range) gives ~1 um feedback; closing the loop on the rail
    cancels the TT gearbox's ~1/4 mm backlash (~260x vs closing on the motor shaft).
    encoder.py: vernier scale physics (geometry->C->phase noise->resolution, absolute
    decode). servo.py: 2-mass belt-drive control proof, rail-loop vs shaft-loop. rail.py:
    build123d CAD (10 watertight parts, scale engraved into the rail). viewer.xml/sim.py:
    MuJoCo playback. Makefile: rail-encod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
    [assembly.step, base.step, base.stl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]
2026-07-09 Add CoreXY control proof on draw-wire (string-pot) encoders
    Applies the load-side-sensing thesis to a 2-axis CoreXY on cheap TT gearmotors.
    drawwire.py: the tape-measure encoder — spring-loaded Dyneema reel + rotary encoder,
    with the reel radius-growth nonlinearity modelled and calibrated (~3 um floor over
    300 mm). corexy.py: the belt-coordinate decoupling (p=X+Y, q=X-Y) reuses the rail-servo
    drive twice under a Cartesian PID + Jacobian mapping; closing on the string encoders
    vs the motor shafts cuts traced-circle error ~8x (backlash) and load droop ~13x.
    make drawwire / make corexy. CAD (frame.py) + MuJoCo viewer still pending.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
    [corexy.py, drawwire.py]
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2026-07-09 Add 2D unrolled magnetostatic FEA cross-check for the PCB motor
    Unrolls the axial-flux motor at mean radius into a Cartesian A_z magnetostatic
    problem (reusing the motor/fea.py gmsh+scikit-fem stack) to PREDICT the air-gap flux that
    motor.py assumes. Result: the assumed 0.25 T was conservative (that's a ~3 mm gap) — a
    realistic 1.2 mm gap with iron flux-returns gives ~0.57 T, so Kt/torque are ~2x the
    conservative estimate. Caveats noted: linear iron (no saturation), slotless iron-return
    config. make pcb-motor-fea. Next: nonlinear iron + true 3D via Elmer.
2026-07-09 Enhance PCB-motor FEA with nonlinear iron + quasi-3D radial sweep
    Recovers most of the value 3D Elmer would add, without the install (Elmer's 24.04
    binary is unsatisfiable on Ubuntu 25.10). Nonlinear iron via a Picard-iterated B-H curve
    clips the unphysical 4.1 T peak to a saturated 2.5 T and shows the air gap is
    magnet-dominated -- B_g is unchanged by saturation, so the ~2.3x flux correction over the
    conservative 0.25 T is real, not a linear-iron artifact. A quasi-3D radial-slice sweep
    (unroll at several radii) captures the end-effect: B_g runs 0.39 T (inner) to 0.67 T
    (outer), torque-weighted to 0.58 T. Corrected Kt ~49 mN.m/A, T_peak ~74 mN.m.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
2026-07-09 Add 2-DOF tendon-driven gimbal (flex): 3 capstans, sprung center
    A rigid 2-axis pan/tilt gimbal pulled by 3 Dyneema tendons at 120 deg off 3 capstan
    motors, recentred by a spring. flex.py: the statics -- pull-only means n+1=3 tendons for
    2 DOF, leaving a redundant co-contraction mode that sets stiffness independent of pose.
    Lean-vector (Rodrigues) pose so azimuth is physical; structure matrix + min-norm/null-space
    tension distribution (all tendons taut, within motor torque); tension-limited reachable
    cone with 3-fold ripple; co-contraction stiffness. cad.py: 7 watertight parts
    (cross-trunnion gimbal). viewer.xml/sim.py: MuJoCo 2-DOF viewer sweeping a 20 deg cone with
    the capstans winding the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
    [assembly.step, base.step, base.stl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]
2026-07-14 Add servo-driven continuum tendril (tendril/): 1 hobby servo, antagonistic TPU finger
    Buildable 1-DOF gripper finger and the real-hardware cousin of flex/: a tapered
    flexible TPU finger bolts (2x M3) into a rigid PLA mount, curled by one MG996R
    whose horn reels an antagonistic Dyneema loop (up channel A, across the tip, down
    channel B). One horn angle -> one bend, both directions, no second motor.
    - tendril.py: planar tapered-elastica statics. Two compliance integrals J1/J2 set
    the transmission (dtheta/dpsi = r_h/d_eff) and the tendon pull; tendon drives the
    proximal tendon_frac with a passive tail beyond. Usable curl 117 deg (horn +-50),
    tension-limited by TPU channel tear-out (~30 N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
    [assembly.step, horn.step, horn.stl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]
2026-07-16 Redesign tendril: segmented vertebrae-on-spine + horizontal-shaft servo
    Per feedback: (1) segment the finger so bending localizes at a flexible spine
    instead of flexing one solid beam, and (2) reorient the servo so the horn spins
    in the bending plane and the strings run straight down the axis (no 90° cable bend).
    - tendril.py: refactored from continuous tapered elastica to a DISCRETE flexure-
    jointed spine. Rigid vertebrae + thin spine gaps (k = E*I_spine/gap); the J1/J2
    sums survive as discrete sums, and a constant tendon offset makes d_eff = d
    exactly. The in-plane horn lever gives ΔL = r_h*sinψ, so the transmission now
    SATURATES near full travel (honest consequence of the reor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
    [assembly.step, horn.step, horn.stl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]
2026-07-23 Add zip-chain linear actuator and Y-zipper stiffness element
    Two zipper-for-rigidity mechanisms as separate deliverables (they share the
    mesh-to-make-rigidity trick but do different jobs):
    - zipchain/ — 2-strip Tsubaki-style rigid-chain LINEAR actuator. Layer-B model
    dominated by the Euler column-buckling envelope (push holds at the 93 N drive
    ceiling to the knee L*=207 mm, then falls to 39 N at full 320 mm extension),
    plus self-locking motor-off hold and compact-coil storage. build123d CAD
    (interlacing comb strands + sprocket + guide head) + MuJoCo deploy viewer.
    - yzipper/ — 3-strip MIT Y-zipper flexible<->rigid STIFFNESS element, built to
    the paper's actual algorithm (CHI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
    [assembly.step, head.step, head.stl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]
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
